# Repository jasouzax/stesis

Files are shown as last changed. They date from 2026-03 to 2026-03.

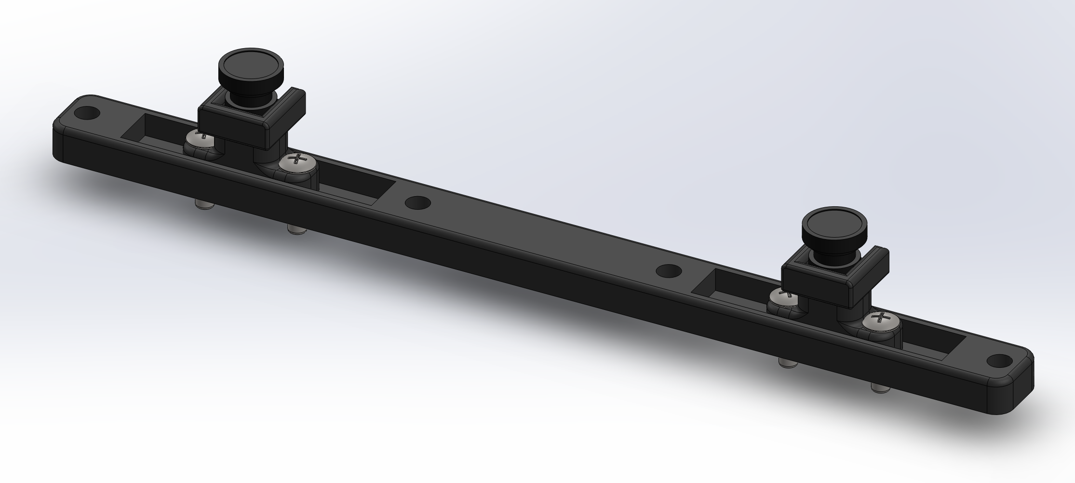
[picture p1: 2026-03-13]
design/images/Screenshot 2026-03-13 at 11.10.45 AM.png

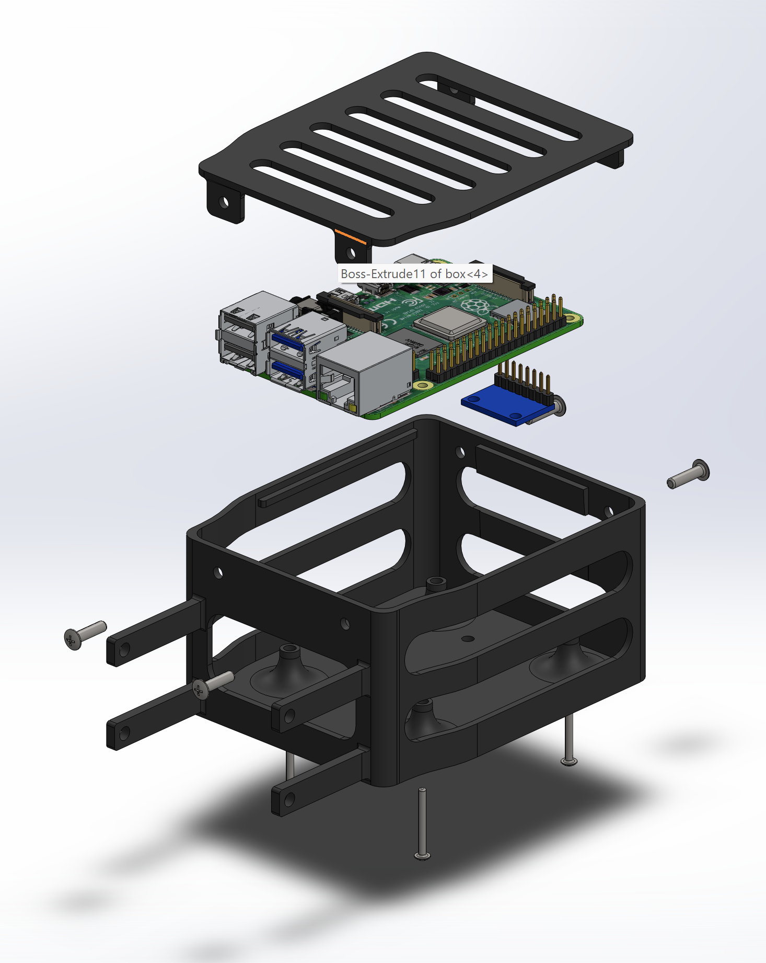
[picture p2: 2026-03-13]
design/images/Screenshot 2026-03-13 at 11.09.35 AM.png

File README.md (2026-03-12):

# Thesis Summary

- [Project Identity](#identity)
- [Project Scopes](#scopes)
- [Problem Statement](#problem)
- [Solution](#solution)
- [Hypothesis](#hypothesis)
- [Objectives](#objectives)
- [Significance of the Study](#significance-of-the-study-rps) *(RPS)*
- [Conceptual Framework](#conceptual-framework)

## Identity

- **Project Name:** Stesis (Stereo-based Sonification Interface System)
- **Thesis Title:** World Navigation Hat – Development of a Wearable Navigation Aid using AIoT for the Visually Impaired
- **Hardware Status:** A single, unified physical prototype is being developed.
- **Publication Strategy:** The research is deliberately split into two distinct papers to prevent copyright and self-plagiarism conflicts:
    - **The IEEE Paper (The Pre-Installed App):** Focuses strictly on the physical navigation algorithm. It evaluates the stereo sonification system, selective filtering via head tracking, and the reduction of sensory overload.
    - **The RPS Paper (The App Manager):** Focuses strictly on the digital/interaction architecture. It evaluates the modular AIoT system, hand-gesture application triggering, server management, and the device's ability to be customized for diverse user needs.

## The Dual-Scope Framework

Because this project addresses the "Valley of death" in Sensory Substitution Devices (sensory limitation/fatigue vs. the generalization problem in real-world environments), it is split into two distinct research tracks.

| Dimension | IEEE Scope (Sensory Limitation) | RPS Scope (Generalization & Integration) |
| --- | --- | --- |
| **Focus** | Minimizing sensory limitations through a radar-like selective filtering algorithm. | Prioritizing AIoT aspects, testing AI/IoT capabilities, and user integration into digital/physical life. |
| **Problem** | Visual Sensory Substitution Devices (VSSDs) fail due to sensory overload, continuously flooding users with audio, preventing "subconscious integration," and causing cognitive fatigue. | VSSDs fail due to integration issues; visually impaired individuals have varied needs, making devices useful only in labs rather than adaptable to real-life scenarios. |
| **Solution** | **Physical Mode (Navigation):** Uses stereo-rectified depth mapping (OpenCV) to convert 3D environments into binaural "radar-like" audio. Local processing ensures <100ms latency. | **Digital Mode (Interaction):** Uses the right camera to detect hand gestures (MediaPipe) to control external AI/IoT applications. |
| **Hypothesis** | Prioritizing selective filtering via intentional head gestures minimizes sensory overload compared to continuous streaming, increasing navigation efficiency and subconscious integration. | Prioritizing a modular system controllable through hand gestures and an IoT server personalizes the device, supporting widespread adaptability. |
| **Objectives** | Develop an AIoT hat minimizing overload via selective filtering. Generate local depth maps via OpenCV. Evaluate cognitive load and navigation efficiency against continuous streaming using a within-subject design. | Build a modular system for third-party AI/IoT apps via NodeJS. Create a toggleable cue mode via hand gestures (MediaPipe) and IMU focus. Test IoT server management, app precision/accuracy, and overall device performance. |

## Objectives (Specific)

- **IEEE** - To develop an AIoT visual sensory substitution hat that minimizes sensory overload by allowing users to selectively filter environmental sonification.
    - Develop a dual-mode prototype powered by a Raspberry Pi 4 that generates local depth maps via OpenCV stereo vision (Physical Mode) and integrates MediaPipe AI hand gesture recognition (Digital Mode).
    - Design a 3D-printed hat mount optimizing weight distribution, powered by a 10,000mAh bank, with modular NodeJS/ElectronJS server for AIoT integration.
    - Evaluate system and user performance using a within-subject design to test the impact of selective filtering on cognitive load and navigation efficiency against continuous streaming baselines.

- **RPS** - To develop an AIoT visual sensory substitution hat that allows applications to be managed in the device with AI and IoT features to allow personalized device to accomidate with Visual Impared People's varied conditions.
    - To build a prototype system that includes:
        - A modular system that allows the development of third party applications for custom modules like AI services, and Server/IoT actions using NodeJS.
        - A toggleable cue mode by hand gesture commands using MediaPipe and using the Inertial Measurement Unit (IMU) to adjust perception focus, to prioritize specific spatial information into audio cues for navigation or to configure external services with the users’ preferences.
        - A stereo rectified sonification system using dual OV5640 stereo cameras and Inertial Measurement Unit (IMU) to convert environmental information through depth maps enabling real-time 3D reconstruction of the environment into audio cues for navigation.
    - To design a portable device that includes:
        - 3D-printed addition on a cap hat to distribute weight evenly and prevent strain on sensitive facial areas like eyes, nose, and ears.
        - Connection to a powerbank placed on the user's pockets to minimize the weight on the head but still power the system
    - To test the functionality of the device system in terms of:
        - Ability to manage applications in the IoT server and its effect in the device
        - Evalulating the Precision, Recall, and Accuracy of the two pre-installed applications of the Toggleable cue interface and the stereo sonification system
        - Measuring the performance of the device running the system

## Significance of the Study *(RPS)*
- **Visually Impaired and Blind Individuals.** They are the primary beneficiaries, gaining increased mobility, safety, and access to digital and social spaces through sensory substitution and IoT assistance.
- **Families and Caregivers.** With the device promoting user independence, caregivers will experience reduced physical and emotional strain while maintaining peace of mind about the user's safety.
- **Medical and Rehabilitation Specialists.** Eye health professionals and rehabilitation centers can use the system as a tool for sensory training and mobility rehabilitation programs, especially to fill in aspects the patient lacks or has trouble with.
- **Researchers and Engineers in Assistive Technology.** The project offers a novel framework that combines virtual world modeling, IoT, and sensory emulation, providing a foundation for future innovations in human-computer interaction and embedded systems. The project can inspire further studies on brain-inspired computing and wearable assistive devices, paving the way for more innovative tools.
- **Government and NGOs for Disability Support.** Organizations involved in disability welfare can adopt or fund similar low-cost solutions to support national accessibility programs and meet inclusive development goals.

## Conceptual Framework 
The IPO of the system is *(Figure 1)*
- **Input**
    - **Hardware**
        - **Raspberry PI 4** - The main microcontroller
        - **10,000mAh Powerbank** - Powers the whole system
        - **Camera (OV5640 5MP/120FOV)** - Captures stereo images in front of the user
        - **Binaural Earphone** - Outputs the binaural audio for user to see through sound
        - **IMU (MPU6050)** - Detects head orientation for interface through head movement
        - **Raspberry PI Cooling Fan** - Responsible for cooling the raspberry PI
        - **3D printed enclosure** - Holds most of the components and sticks to the hat
        - **Hat Cap** - The hat placed on top of the user and holds the enclosure
    - **Software**
        - **VSCode** - Main IDE used in the system's development
        - **Arduino Studio** - Development of the android app for APIs passthough
        - **SolidWorks** - Creates the 3D model of the 3D printed enclosure
        - **GitHub** - Manages the project codebase and files
    - **Connectivity Protocols**
        - **WiFi** - This allows the device to connect to the IoT server, as a hotspot by the phone to provide internet and phone sensor data through the android app
        - **I2C** - Connection to read gyroscoping and accelerometer data from the IMU
- **Process**
    1. Problem Statement
    2. Literature Review (RRL)
    3. Prototype
        1. Requirements
        2. Designing
        3. Development
        4. Refinement
        5. Implementation
        6. Testing
    4. Data Recording
    5. Data Analysis *(IEEE)*
        1. Latency from capture to output
        2. Accuracy of IMU and AI
        3. Stereo Calibration Scopes
        4. Navigation Metrics
        5. Cognitive Load (NASA-TLX)
        6. Intuitiveness (Wilcoxon Signed-Rank Test)
    6. Data Analysis *(RPS)*
        1. Device's performance (weight, latency, etc.)
        2. Server's performance (latency, security, etc.)
        3. Gesture accuracy (head and hand gestures)
        4. Navigation ease of use survey
- **Output** - Development of the wearable navigation aid using AIoT for the visually impared named Stesis
- **Feedback** - Feedback from the output to redesign back to the input as to improve the system

## Related Studies

* [**Louis Commere, and Jean Rouat (2023):**](https://arxiv.org/pdf/2304.05462) The most newest visual sensory subtitution device that both uses depth and sonification, being the most closest to our study and will be used as the baseline to test the null hypotesis. *Limitation:* It provides only localized, single-target directional information, severely restricting global scene comprehension. Users cannot perceive a general room outline simultaneously; instead, they are forced into tedious, sequential "Roomba-like" scanning and must rely heavily on working memory to construct a complete spatial map.
* [**Eye-Tracking Sonification (2025):**](https://doi.org/10.3389/frvir.2025.1598776) Filters VR environments using eye-tracking. *Limitation:* Not tested on real-world visual data; relies on eye movement, which may not be functional for all visually impaired users.
* [**Sound of Vision (2018):**](https://doi.org/10.1097/OPX.0000000000001284) Generates continuous 3D audio-haptic maps. *Limitation:* Suffers from sensory overload affecting long-term adoption. Stesis addresses this via gesture-based filtering.
* [**Eye Cane (2015):**](https://doi.org/10.3233/RNN-130351) Uses infrared for single-point distance sound. *Limitation:* Lacks the spatial context and "scene outline" Stesis provides.

## Theoretical Basis

- **Sensorimotor Contingencies:** Allowing direct control over input shifts cognitive load from conscious decoding to intuitive subconscious spatial awareness.
- **Radar-Like Mapping:** Substitutes 2D visual data into 1D audio by representing the Y-axis as audio and the X-axis as time.
- **Scene Gist and Gestalt Organization:** Humans perceive geometry outlines before details. Stesis uses depth maps via stereo rectification for real-time spatial geometry processing (faster than AI models like MiDaS).
- **Equal Loudness Compensation:** The closest proximity in a time slice is represented in audio; frequency is inversely proportional to proximity, and compensation ensures it doesn't affect volume perception.
- **Head-Related Transfer Function (HRTF):** Volume is split between left/right channels to create 3D space awareness.
- **Focus, Spatial Resolution & Saliency:** Radar scan rate is proportional to the device's angle of depression. Over time, the radar loses total volume to reduce redundant data, prioritizing new movements as visual selective attention.

## System Design

The device first runs the main service which connects to a hotspot or wifi so that it can use server APIs and the internet, then activating the device application running the installed applications. There are two pre-installed applications:
- **Hand Gesture** - This application is activated if the IMU detects that the user is facing to their right hand *(down and rolled/turned facing the right side)*, it captures the right camera and detects the hand guesture through MediaPipe AI. If the hand guesture matches a specific hand guesture then it activates its corresponding action.
- **Stereo Sonification** - This application is activated if the IMU detects that the user is facing downwards indicating they want to see their obstacles to navigate. It captures the stereo images from the two cameras where stereo rectification is applied to generate the depth map, it is then processed to generate a radar map of the environment and then sonified to represent that data as audio to the binaural earphones.
The device can make a request to the server to access these third party applications through an Android phone that provides the internet access and other details like GPS or Compass. The server side hosts to the internet through cloudflare and accepts an API or cargiver/user side access with authentication details of the Device ID and password, the interface shows the third party applications the device installed and other important details like last used or device information for caregiver monitoring.

The device itself contains the following components:
- **Raspberry PI 4** - The central microcomputer running the client side program *(5.5W active, 3W standby)*
- **MPU6050** - The IMU that measures the head orientation *(0.1W active and standby)*
- **OV5640 Cameras** - Placed 13cm apart from each other and provides the stereo images *(2W active, 0.5W standby)*
- **Stereo Earphone** - Provides the audio output generated from the client side program *(0.1W active, 0W standby)*
- **Raspberry PI Fan** - Cools the device and prevents overheating *(0.5W active, 0.2W standby)*
- **Powerbank** - A 10,000mAh powerbank that should be in the user's pockets *(10Ah$\times$3.7V$\times$0.85 efficency=31.45Wh)*
- **Cables/Wires** - Connects each components to each other
- **Case** - A 3d printed case that holds every component except for the powerbank
- **Cap Hat** - The case is glued to the hat to hold everything in place

The expected duration of the device is from 8.27 hours at standby $(\frac{31.45}{3+0.5+0.2+0.1+0}=8.27h)$ to 3.83 hours at continuous active navigation $(\frac{31.45}{5.5+2+0.5+0.1+0.1}=3.83h)$.

The software dependencies of the client side is as follows:
- **Raspberry PI OS** *(OS)* - The main operating system the client device is in
- **Python** *(Programming Language)* - The main framework the client side program is running in
- **Conda** *(Environment Manager)* - Responsible for managing the python environment
- **SocketServer** *(Library)* - To host the client side device info website
- **Requests** *(Library)* - Connects to the server side AIoT server

The pre-installed applications uses these dependencies:
- **OpenCV2** *(Library)* - Does the stereo vision and image processing
- **SMBus** *(Library)* - Allows communication through I2C especially for the IMU
- **Numpy** *(Library)* - Helps manage process data/matrices
- **MediaPipe** *(Library/AI)** - Detects the hand gesture from the image
- **PyAudio** *(Library)* - Connects to the earphones allowing to play generated audio

The codebase of this client side uses a modular design where each module represents a class with their own responsibility, this makes applications their own class with their dependencies being parent classes allowing easy tracking of application dependencies. The pre-installed modules are:
- `main.py` (loads `hand` and `audio` because their applications) - This module hosts the device info website and switches between the depth map sonification processes `audio` and the modular application calling `hand` based on the reading of the IMU
- `config.py` - This is where all of the configurations of the device is stored in
- `camera.py` (from `config`) - This module connects to the stereo cameras to read the images
- `imu.py` (from `config`) - This module reads from the IMU through I2C and processes the device orientation details
- `calibrate.py` (from `camera`) - This module is ran directly to calibrate the depth map generation by generating the stereo rectification JSON `stereo-{baseline}.json`
- `depth.py` (from `camera`) - This module generates the depth map by using the `stereo-{baseline}.json`
- `radar.py` (from `depth` and `imu`) - This module maps the depth map to the radar map
- `audio.py` (from `radar`) *(Main Application)* - This module sonifies the radar details as audio output to the earphones
- `hand.py` (from `camera`) *(Main Application)* - This module detects the hand guesture of the right camera through MediaPipe AI, and triggers their associated action
- `rrl_kchr2023.py` (from `camera`) *(IEEE only)* - This is the algorithm based on (Louis Commere, and Jean Rouat 2023) to be ran on State A as a comparision to the research's algorithm.

The device connects to the AIoT server through an Android phone that hosts the hotspot, providing the internet, GPS, Compass, etc. The software dependencies of the android phone are as follows:
- **Kotlin** - Programming language to program the app logic/server.
- **Google Mobile Services (GMS)** - Provides APIs for the app to forward to the device like `play-services-location` for GPS location.

The server side uses the following software dependencies:
- **NodeJS** - The main framework of the server side process
- **TypeScript** - Allows stricter type checking to prevent server side issues
- **ElectronJS** - Creates an application compiled format, and allows advance API/Automation
- **Ollama** - Connects with Langauge Models for advance intellegence requests
- **Cloudflare** - Allows server to be hosted through a cloudflare tunnel through tunneling

For the softwares/tools used for development includes:
- **VSCode** - IDE for developing client-side and server-side codebases
- **Android Studio** - The software used to develop the android application
- **SolidWorks** - CAD software to develop the 3d case model
- **Github** - Manages the entire codebase, versions, and distribution

## Stereo Rectification Calibration

To calibrate the stereo vision, 3 baseline was tested 8.75cm (minimum), 10cm, and 13cm (maximum). For image training/calibration, 22 images where provided where 9 of them are the sides top/middle/bottom and left/middle/right, for both close and far (so total 18). Four other images angled top, bottom, left, and right were added totaling 22 images. The statistics like Root Mean Square (RMS) pixel error and minimum/maximum detectable range are:

| Baseline (cm) | Calculated (cm) | RMS Both (px) | Minimum (cm) | Maximum (cm) | FOV Left | FOV Right | RMS Left (px) | MS Right (px) |
| - | - | - | - | - | - | - | - | - |
| 8.75 | 8.7861 | 1.7393 | 7 | 90 | 112 | 112.88 | 1.3914 | 1.3963 |
| 10 | 10.66 | 1.5494 | 15 | 100 | 113.19 | 113.32 | 1.2314 | 1.2314 |
| 13 | 13.0646 | 1.4055 | 24 | 130 | 112.52 | 111 | 1.0852 | 1.181 |

Since the equation for depth $Z=\frac{f\cdot b}{d}$ shows that depth is linear if the focal length $(f)$ and baseline $(b)$ are constant, the minimum and maximum depth for a specific baseline can be represented as $Z=Ab+C$. Through assuming linear trend the minimum depth is $Z_{min}=4b-26.5$ while the maximum depth is $Z_{max}=9.3b+8.5$. Since our target range is for close quarter navigation (rooms, corridors, buildings, etc.) 130cm max depth detection is perfect for range detection, even for close outdoor navigation.

## Benchmarking & Testing *(IEEE)*

The study employs a **Within-Subject** design with 40 blindfolded participants comparing **State A** (Continuous Stream) vs. **State B** (Stesis Selective Filtering) on a controlled obstacle course (Our school classrooms and corridors). As for the modular system, the user test if they could successfully call a mockup call through hand gesture.

**Comparitive/Baseline Methods (State A)**
Continuous streaming will implement existing visual sensory substitution to audio algorithms to provide a better comparision to the Stesis Selective Filtering algorithms. The algorithm is based on [Louis Commere, and Jean Rouat (2023)](http://arxiv.org/pdf/2304.05462) which uses the beep-repetition rate has it remains the gold standard baseline for non-verbal spatial warning systems.

**System Performance Metrics:**

- **Latency:** Time from capture to audio output (Target: <100ms).
- **Accuracy:** Reliability of Head (MPU6050) and Hand (MediaPipe) gesture recognition.

**User Performance Metrics:**

- **Navigation:** Time to Completion (TTC), Obstacle Hits (OH), and Veering (lateral deviation).
- **Cognitive Load:** NASA-TLX (Task Load Index) survey to quantify mental fatigue.
- **Intuitiveness:** Wilcoxon Signed-Rank Test on user feedback.

**Statistical Analysis:**
A Paired T-Test will be used for TTC and OH. If the null hypothesis is rejected, indicating that gesture-based filtering significantly improves performance.

## Benchmarking & Testing *(RPS)*

- **Testing Methodology:** Users test the modular system by attempting to successfully trigger a mockup call through a hand gesture.
- **Application Management:** Evaluating the system's ability to manage applications within the IoT server and its overall effect on the device.
- **Hardware & Server Performance Metrics:** Measuring the physical device's performance (such as weight and latency) alongside the IoT server's performance (including latency and security).
- **Interface Accuracy Metrics:** Evaluating the Precision, Recall, and Accuracy of the two pre-installed applications (the toggleable cue interface and the stereo sonification system) as well as the gesture accuracy for both head and hand movements.
- **User Experience:** Conducting a navigation ease-of-use survey.

## Implications and Future Work

- **Digital Integration:** Potential for managing social media interfaces, text recognition, and API integration via gestures.
- **Hardware Evolution:** The selective filtering software concept can be adapted to existing smart glasses using LiDAR or eye-tracking.
- **Future Interventions:** Exploring hybrid audio-tactile feedback to reduce fatigue and conducting longitudinal studies with visually impaired users. This prototype is a foundational validation of the controllability hypothesis.

## Design Backstory & Rationale

- **The Hardware Pivot:** The prototype utilizes a **Raspberry Pi 4** rather than the smaller Orange Pi Zero 2W. While the Orange Pi offered better portability, it presented critical stability issues (WLAN failures on Debian, I2C kernel conflicts) that hindered development. The RPi 4 provides the architectural stability necessary to validate the *software hypothesis* (selective filtering), which takes precedence over miniaturization in this phase.
- **Why a Hat?** Distributing hardware weight across the cranium avoids the nose/ear fatigue common with smart glasses. Additionally, the stereo camera spacing on the brim mimics the natural separation of human eyes, aiding the brain in depth perception and sonification.
- **Nomenclature:** "Stesis" is a triple-entendre: **Ste**reo-based **S**onification **I**nterface **S**ystem, while the suffix "-sis" nods to its dual nature as a Thesis and a Hypothesis.

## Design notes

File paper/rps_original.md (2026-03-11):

  
**World Navigation Hat \- Development of a Wearable Navigation Aid using AIoT for the Visually Impaired**

An Undergraduate Design Project Proposal Presented to Faculty of the Computer  
Engineering Department of College of Technology University of San Agustine

In Partial Fulfillment of the Requirement of the Course  
**CPE 413 \- CpE Practice and Design I**

**By:**  
Daywan, Vince Ginno B.  
D’Souza, Jason C.  
Pabito, Ethel Herna C.  
Wang, ChenLin

Engr. Glenda S. Guanzon  
November 2025  
**Introduction**

# **Background of the Study**

Visual impairment is a global health problem that significantly affects individual's daily lives by impeding independent navigation, social interaction, and overall quality of life (Theodorou et al., 2023). There is an estimation of 2.2 billion people globally who are identified as visually impaired and this number could still increase to 2.5 billion by 2050 as stated by the World Health Organization (World Health Organization, 2023). In the Philippines, 2.17 million Filipinos are identified as visually impaired as quantified by reports from the year 20218 from the Philippines Eye Research Institute (PERI) and Department of Health (DOH) (Shinagawa Lasik & Aesthetics, 2025). Visual impairment does not pertain to total blindness. According to World Health Organization (2023), visual impairment can be identified and categorized based on the presenting visual acuity; 

a) Mild Vision Impairment, as visual acuity is better than 6/18, 

b) Moderate Vision Impairment, as visual acuity is worse than 6/18 but better than 6/60, 

c) Severe Vision impairment, as visual acuity is worse than 6/60 but better than 3/60, 

d) Blindness, as visual acuity is worse than 3/60, types such as blindness with light perception, individuals can only perceive light, and total blindness, individuals who have no light perception. 

Other common types include astigmatism, near-sightedness (myopia) and far-sightedness (hyperopia), which account for a large share of impairments, alongside conditions like cataracts, glaucoma, and age-related macular degeneration (AMD), with AMD alone affecting 8.06 million people globally in 2021 (Zou et al., 2024).

Navigation is one of the problems visually impaired people (VIP) encounter, they often have difficulty crossing the road and tracking their location, as well as experiencing accidents, falls, and collisions (Ikram et al., 2024; Gao et al., 2025; Muhsin et al., 2023).   
In addition, VIPs experience social isolation and reduced access to information, limiting their educational and employment opportunities (Arvind, 2023). There are already existing solutions or aids for VIPs, for daily assistance, which include guide dogs, white canes, and electronic travel aids (Muhsin et al., 2023). Additionally, one of the technologies VIPs depend on for navigation is assistive devices, which use sensory substitution to convert visual information into auditory or tactile cues to provide spatial awareness (Skulimowski, 2025). These devices often incorporate IoT sensors to capture real-time environmental data, providing navigational assistance in complex environments (Real & Araújo, 2023).

Sensory substitution devices (SSDs) are assistive wearable devices that can be eyewear, a vest, or a hat, allowing VIP users to perceive their surroundings by converting sensory information from one modality to another (Mishra et al., 2025). These SSDs are embedded with sensors that allow obstacle detection, navigation, and object recognition, enhancing VIPs' daily independence and reducing their reliance on traditional aids (Tokmurziyev et al., 2025). However, global adoption of these devices is limited due to cognitive overload performance, extensive training needs, ergonomic discomfort design, and the lower processing bandwidth of non-visual senses compared to vision (Hou et al., 2025).

# **Rationale**

Visual Impairment encompasses a spectrum of conditions, from moderate vision loss to complete blindness, which significantly impacts an individual's ability to perceive their environment and perform daily activities (Kumar et al., 2025). This condition also affects the individual’s social interaction and overall quality of life (Que et al., 2025). More than 2.17 million people in the Philippines live with visual impairment, which restricts their perception, mobility, navigation, and accessibility to information—depriving them of work opportunities and independence (Chavarria et al., 2025). To mitigate the challenges encountered by the VIP, assistive technologies and rehabilitation strategies have been developed (Skulimowski, 2025). Traditional assistive aids like white canes offer limited feedback, initiating the development of electronic travel aids that deliver richer environmental information and improve autonomous navigation (Chandra et al., 2025). Another solution is a wearable SSD, an assistive technology that an individual can wear on their body to help users navigate both their physical surroundings and digital applications, and emerging as a potential avenue to restore or gain a sense of spatial perception or awareness and navigational ability (Skulimowski, 2025). Additionally, SSDs promote social interaction that aligns with one of the United Nations' Sustainable Development Goals for health and equality (Xue et al., 2025).

In previous studies, SSDs have been limited in their applicability, as existing devices often perform poorly in real-world situations, encountering cognitive overload problems that overwhelm users with excessive information, making navigation difficult (Arora et al., 2024). Another identified concern is that the SSD design is uncomfortable, as it is bulky and requires extensive training, which limits its practicality (Gao et al., 2025; Muhsin et al., 2023, p. 148). In addition, many of these devices lack digital integration as capabilities, focusing mainly on obstacle detection and not connecting well with digital tools (Makati et al., 2024). These deficiencies underscore the pressing need for higher SSDs that can outperform and enhance existing devices. Therefore, a need for development of optimized smart navigation devices improves the functional efficiency and performance of SSDs without overlooking the previous concerns like overloading data processing.

In this study the researchers aim to address these matters through the development of a wearable navigation hat integrated with AIoT, which introduces a smart navigation hat that uses 3D data to give audio feedback and connects to IoT services for navigation in both physical and digital environments. Furthermore, it enhances sensory processing, focusing on reducing cognitive overload in the system and making navigation simpler for VIP users. Additionally, the hat features customizable options, including a modular operating system that allows users to choose between hand gesture or voice commands.

# **Objectives of the Study**

## **General Objective**

To develop an AIoT visual sensory substitution hat device that converts real-time environment information through emulating human sensory processes into audio cues for the VIP.

## **Specific Objectives**

1) To build a prototype system that includes:  
1) A photogrammetry (2D to 3D) system using dual OV5640 stereo cameras and Inertial Measurement Unit (IMU) to convert environmental information through depth maps enabling real-time 3D reconstruction of the environment into audio cues for navigation.  
2) A toggleable cue mode by hand gesture commands using MediaPipe and using the Inertial Measurement Unit (IMU) to adjust perception focus, to prioritize specific spatial information into audio cues for navigation or to configure external services with the users’ preferences.  
3) A modular system that allows the development of third party applications for custom modules like AI services, Server actions using NodeJS, and hand gesture recognition.

2\)	To design a portable device that includes:

1) A rechargeable 5V/3A UPS module with 18650 lithium-ion batteries for cord-free operation via Type-C charging.  
2) 3D-printed hat enclosure to distribute weight evenly and prevent strain on sensitive facial areas like eyes, nose, and ears.

3\)	To test the functionality of the device system in terms of:

1) Calculating the Error and Success Percentage performance of photogrammetry by comparing the generated depth maps to ground truth measurements.  
2) Evaluating the Precision, Recall, and Accuracy of the toggleable cue mode hand gesture commands responsiveness to switching modes.  
3) Measuring the frame per second (FPS) of AI processing, error rates in recognition, and route accuracy of the modular system.  
4) Simulating full system functionality by combining photogrammetry, IMU, and modules to track overall FPS, audio cue fidelity, and failure cases, with qualitative feedback from the users using surveys.

# **Significance of the Study**

This project device will specifically benefit to the following:  
**Visually Impaired and Blind Individuals.** They are the primary beneficiaries, gaining increased mobility, safety, and access to digital and social spaces through sensory substitution and IoT assistance.  
**Families and Caregivers.** With the device promoting user independence, caregivers will experience reduced physical and emotional strain while maintaining peace of mind about the user's safety.  
**Medical and Rehabilitation Specialists.** Eye health professionals and rehabilitation centers can use the system as a tool for sensory training and mobility rehabilitation programs, especially to fill in aspects the patient lacks or has trouble with.  
**Researchers and Engineers in Assistive Technology.** The project offers a novel framework that combines virtual world modeling, IoT, and sensory emulation, providing a foundation for future innovations in human-computer interaction and embedded systems. The project can inspire further studies on brain-inspired computing and wearable assistive devices, paving the way for more innovative tools.  
**Government and NGOs for Disability Support.** Organizations involved in disability welfare can adopt or fund similar low-cost solutions to support national accessibility programs and meet inclusive development goals.

# **Conceptual Framework**

[**Figure 1**](https://docs.google.com/document/d/1N4Ya048OJufQJaMhjFfynmU-Aq_rgIfC3wOmSFFCeBE/edit#figur_ipo)  
*IPO Model of the Conceptual Frame of the Study*

Figure 1 illustrates the study's conceptual framework as an Input-Process-Output (IPO) model. Starting with three kinds of required input, such as the hardware components Microcontroller, Sensors, Actuators, SIM Module, and Wireless Connectivity, used on the device, which can be either 2/3G used for deployment doors, or Wi-Fi as used in deployment indoors or development. In addition to the input, the software components include Project management, Client-side device, and Server-side device. After the input, it will proceed to the process, which includes the following: 1\) Problem Statement, 2\) Literature Review, 3\) Prototyping, which includes Materials Requirements, Device Design, Development, Refinement, and Implementation, 4\) Data Recording, 5\) Data Analysis of the findings using P-test on the Device Performance in terms of accuracy in recognizing user controls (hand gestures) and generating relevant audio from environmental inputs; Sensory Overload on user accuracy in interpreting generated audio cues (e.g., via task completion rates) and qualitative feedback on perceived overload on user; Sensory Fatigue on usage duration before symptoms like headaches emerge (e.g., via self-reported scales, physiological monitoring, or user surveys); Sensory Integration in tracking reaction times to environmental data, learning curves over sessions, and survey responses on ease of subconscious adaptation. The research process mimics typical development cycles, including literature review, prototyping, designing, testing/evaluation, and implementation. By the end of each iteration, the researchers expect to be closer to the end goal, with user and professional feedback to start the cycle again until the end goal of a wearable navigation aid is achieved.

# **Theoretical Framework**

This research attempts to solve an issue facing most Visual Sensory Substitution Devices which is primarily about the issue on translating a high bandwidth visual information to low bandwidth audio information without causing overstimulation, our novel solution is the emulate the human sensory mechanism to carry the processing load from the user and ensure that substituted information is minimal and necessary to the user. The theoretical principles include:

**Focus and Spatial Resolution (Foveation)**   
The human vision has a tiny high-resolution fovea covering around 1 to 2 degrees of the visual field but accounts for around half of visual cortex (Himmelberg et al., 2023), outside this region is a much coarser peripheral vision where acuity drops rapidly (Aydin et al., 2024). In this study, the device attempts to mimic this by using a focus point system where the user can contain the focus radius indicating that area of the environment the user wants to be translated into audio and at what detail.

**Selective Attention and Saliency**   
As the visual system cannot process all details at once, it selectively attends to salient or task-relevant features, this is done by implementing a bottom-up saliency and top-down goals to filter out redundant/irrelevant information (Arora et al., 2025). This demonstrates that people focus on key objects ignoring uniform backgrounds as the nervous system "tunes out" repeated stimuli and amplifies novel/focused ones (Gershman, 2024). The device translates environmental information where any stagnating/constant information must be tuned out over time leaving behind changes indicating motion.

**Scene Gist and Gestalt Organization**

Human vision rapidly extracts the gist (background) and figures (foreground) from a scene within the first fixation (\~36ms) with around 80% accuracy (Loschky, 2025). This process is done through Gestalt principles that groups elements to simplify complex images such as by similarity, proximity, common region, continuity, etc. (User Testing, 2024). This indicates that the device should be able to generally/primitively separate the environmental data into background and foreground categories where foreground can then be separated into groups, this is information to indicate the translated audio.

**Parallel Motion vs. Detail Pathways**   
Human visual systems process motion and details in two separate channels, the magnocellular pathway for fast motion and size but in less detail, and the parvocellular pathway for static objects in more detail (Al-Najjar et al., 2022). Suggests that when the device switches to motion detection it should prioritize the speed, size, and direction of that motion.

**Temporal Dynamics and Scanning**  
Vision is not a singular static snapshot but rather a continuous sample of the world via eye movements has humans typically shift gaze 3-4 times a second (Nghiem et al., 2025). Thus, in this study, the device should rapidly provide updating audio to allow temporal integration rather than one large static soundscape all at once, this also solves the issue of cognitive overload and sensory fatigue.

**Multisensory Integration**   
The brain integrates additional senses like auditory, vestibular, and proprioceptive senses to form a coherent representation of the environment (Multisensory Integration, 2025). Thus, the device should align with those senses to prevent conflicting senses that could often cause nausea. This could be in the form of aligning the virtual environment with IMU to align with vestibular senses, or lower the output audio when the user is focusing on something else like talking to others.

**Scope and Delimitation**  
This research study focuses on Sensory Substitution Devices, more specifically on Vision Substitution. The device aims to fill in what different variety of visually impaired individuals lacks, like if fully blind the device should be able to act as an “artificial eye” providing information the person wants, or if the person is near sighted it could read text from afar from the user and warn of objects rapidly approaching the user, and so on. This is done by having a modular system running the main pipeline, the main pipeline inputs images from the stereo camera, depth map it to a virtual-physical map, follows an algorithm to emulate human vision processes, and finally generates the necessary audio cues for the individual. This pipeline allows applications to take into account more varied needs such as hand gesture recognition to control the parameters of the main pipeline so the person can navigate the device without seeing anything, image recognition to read text near or far, face recognition to recognize friends and family, and even more personalized interest like keeping track of location. In the testing, the device will only prioritize the functionality and feasibility of the system to determine if the designed and developed project can perform efficiently. Mock API will be utilized to demonstrate the potential functionality of external services of the system. 

# **Review of Related Literature**

Zvorișteanu et al. (2021) presented the Sound of Vision (SoV) system. It is a wearable SSD designed to aid VIPs in spatial cognition and navigation, using stereo-vision-based 3D reconstruction to interpret the environment and translate spatial data into audio and haptic cues. The device integrates a stereo camera, an infrared depth sensor, and an inertial measurement unit (IMU) to track the motion of the user’s head and the installed camera mounted on the headgear, using these as its inputs. Furthermore, the output audio and haptic feedback are delivered via headphones and a haptic belt. The device processes visual data in real time using GPU-accelerated computation to reconstruct the 3D Environment and identify obstacles via segmentation algorithms based on disparity and histogram analysis. The depth of each pixel is determined by the stereo disparity formula Z=f⋅Bd, where Z is the depth, B is the baseline, f is the focal length, and d is the disparity. The SoV converts environmental data into audio-haptic cues, allowing users to detect obstacles, open spaces, and open areas. In testing the device's performance with the visually impaired participants, it showed a 10% improvement in depth accuracy and an 88.5% task success rate compared to standard stereo vision methods. The results highlight the device's effectiveness in real-world navigation and its potential to enhance mobility and spatial awareness compared to traditional aids such as white canes.

Sami et al. (2025) developed a smart wearable (hat) assistive device that integrates object detection with voice-assisted navigation to support VIP in real-time spatial awareness. The device uses an ESP32-CAM module to capture live video and transmit it via Wi-FI to a mobile application that employs a TensorFlow-based deep learning model for efficient object recognition. The camera-detected objects are then processed into audio prompts that send alerts to the user when there are nearby obstacles and provide navigation directions. The programmed system produced a seamless object-detection-to-voice pipeline. The Smart Hat's system architecture demonstrates the integration of an IoT processing method to enable wireless communication between the smart hat and the user interface for remote processing and real-time updates for the user. Testing results show an object detection accuracy of over 91%, highlighting the reliability in dynamic environments. In addition, the Smart Hat device offers compact, low-cost, and user-friendly features. It demonstrates how IoT-enabled computer vision can transform traditional assistive technologies into intelligent, voice-guided navigation tools for the visually impaired.

RealSense (2025), in collaboration with Eyesynth, developed a wearable sensory-substitution device designed to enhance spatial awareness and independent navigation for visually impaired users by converting real-time 3D spatial data into bone-conduction audio cues. The device employs the RealSense D415 depth camera to capture real-time 3D depth data calculated using the stereo disparity formula Z=f⋅Bd. Then it is processed to generate a point cloud representation of the surroundings, where each depth pixel being mapped to 3D coordinates using the equation X=u-cxzfx, Y=v-CyZfy, Z=Z to provide a complete spatial surrounding rather than a 2D view. The point-cloud data conjoint with the inertial and head motion tracking, is then processed through an onboard ASIC and Simultaneous Localization and Mapping (SLAM) modules to identify object orientation, translating them into audio signals such as pitch (height), volume (distance), and stereo panning (lateral position), allowing users to perceive objects and obstacles up to 5 meters away without external infrastructure. In testing NIIRA, it demonstrated improved independence and navigation in both indoor and outdoor environments, adapting to users’ preferences, and displayed high obstacle-detection accuracy, minimal processing latency, and enhanced independent navigation. The participants reported that the bone-conduction audio feedback provided a clear environmental awareness without blocking external sounds.

Udayakumar et al. (2025) designed a Smart Vision Glasses (SVG) that processes environmental input data using AI, LiDAR depth mapping, and computer vision algorithms. The device’s front-facing camera captures visual data, while the LiDAR sensor measures real-time depth information using the principle of Time-of-Flight (ToF) – where the distance (D) is calculated using the formula D=c⋅t2, where c represents the speed of light and t the time taken for emitted light to return after reflection. These depth and image data are then processed through an AI-based recognition model that uses Convolutional Neural Networks (CNNs) to classify objects, text, and faces within the user's field of view. The recognized elements are subsequently analyzed and prioritized based on proximity and relevance using the LiDAR-assisted spatial mapping, which produces a semantic understanding of the scene; implementing Volume of Interest (VOI), a controllable spatial region or focus radius that limits feedback, to prevent sensory overload, enhancing user focus in dynamic environment. This processed information is then transmitted to a smartphone-based application converting the recognized data into voice audio cues through text-to-speech (TTS) engine. The device applies natural language processing (NLP) principles to ensure that the audio output is contextually meaningful and user-friendly. The input-output process follows a sequential pipeline:

1) capture of the image depth data  
2) AI-driven detection and classification  
3) distance estimation through the ToF equation  
4) conversion of results into voice audio output describing nearby objects, text, or faces. 

The SVG through hearing supports the four primary modes – “Thighs Around You”, “Reading”, (Walking Assistance), and “Face Recognition”. The SVG is also equipped with gesture and voice control interfaces, allowing users to switch modes or issue commands hands-free, enhancing accessibility and user interaction. A multicenter usability study was conducted across five rehabilitation centers in India, involving 90 participants with a mean age of 23.5 years, to test the device functionality. The participants tested the four primary modes by completing real-world navigation and recognition tasks, and their feedback on the device's usability and helpfulness was also recorded. Results showed that 72.9% indicated that "Reading” mode is helpful, 44.7% for “The Things Around You”, 36.5% for “Face Recognition”, and 22.4% for “Walking Assistance”, showing that the device effectively enhances environmental awareness, reading ability, and object identification.

Ruan et al. (2025) developed a multifaceted sensory substitution wearable device that uses an audio-based curb detection to improve real-time awareness and navigation safety for individuals who are blind or have low vision. The device integrates a stereo camera, ultrasonic range sensors, and inertial motion units (IMUs) to identify curbs and ground-level transitions Adapting the stereo disparity formula Z=f⋅Bd, the system calculates the curb height and distance, while the ultrasonic sensors confirm the surface proximity of the environment for redundancy and accuracy. The sensory data are processed and converted into audio and vibrational cues, where the pitch and repetition rate of the sound correspond to the curb’s distance and height, providing intuitive, time-sensitive feedback. In the pilot testing, 12 participants were involved, 8 with blindness and 4 with low vision. The participants tested the navigation feature of the device in both indoor and outdoor test environments, including simulated sidewalks, ramps, and descending curbs. After testing, the performance statistics of the device showed an average curb detection accuracy of 94.3%, with a false-negative rate of 3.7%, and an average alert response time of 1.2 seconds, indicating the system’s reliability in detecting and signaling curbs in real time. Participants reported that it also improved confidence in mobility and reduced the risk of missteps or trips. This demonstrates that the audio-based curb detection approach driven by LiDAR-like depth estimation and multimodal feedback effectively enhances real-time alerting and safe navigation for the VIP.

Viancy V et al. (2024) introduced AuralVision, a wearable assistive device that is designed as eyewear to improve navigation for visually impaired individuals by incorporating object detection, scene classification, and reinforcement learning. The device's system architecture includes a camera sensor to capture the user’s environment, image-processing and object-detection software to classify obstacles and identify significant objects, and an audio module to translate detection results into auditory cues for navigation. Utilizing a convolution neural network (CNN) approach or deep learning-based vision algorithms trained on the Object Net 3D dataset to interpret the surrounding environment and convert the visual information to auditory cues that convey spatial awareness. AuralVision uses 3D visualization and sound-based feedback to identify objects, classify road scenes, and assist users with obstacle avoidance and pathfinding. The device adapts to dynamic environments through continuous learning, thereby improving navigation decision-making.

Hamilton-Fletcher et al. (2021) developed a mobile sensory-substitution device called SoundSight. This device translates input color, depth, and temperature data into output audio cues, allowing the visually impaired users to sense their environment. The system captures environmental input using a mobile with an RGB-D camera and a thermal sensor. Then it processes the data stream through a multi-feature mapping pipeline before integrating it into a composite audio stream. Depth is calculated using the stereo disparity formula to determine the distance of the object from the user's perspective. At the same time, the RGB camera's color hue values are mapped to sound pitch using the equation fc=kc×H, where H represents the hue intensity and scaling constant. Temperature measurements are converted to amplitude modulation through At=kt×T, where T is the sensed temperature and kt is a sensitivity coefficient. These parallel mappings are integrated using the data fusion algorithms, synchronizing depth, color, and thermal inputs before generating the composite audio streams that encode environmental depth through rhythm, color through pitch, and temperature through loudness. In testing the device's functionality, 15 blind and 10 low vision participants are involved. The device demonstrated rapid user learning and over 85% recognition accuracy, demonstrating that the multi-feature sonification can reliably convey complex environmental information.

Han et al. (2025) designed a Multi-Path Sensory Substitution Device (MSSD) that enhances low-vision mobility and virtual navigation of the visually impaired people by integrating real-time depth mapping, IMU-based motion tracking, and depth optimization algorithms. The system processes input from a depth camera and inertial sensors to create a 3D spatial model of the environment, using the stereo disparity equation to calculate object distance and the projection model X=u-cxzfx, Y=v-cyzfy, to map each pixel to world spatial coordinates. After acquiring the data from the processed input, it generates a 3D point cloud, which then is converted into an occupancy grid for spatial awareness, while the IMU readings refine user orientation using the equation t=t-1+ωtΔt. A modified A\* (A-star) algorithm is used to compute the optimal navigation routes using the cost function fn=gn+hn, balancing actual distance and heuristic estimates to avoid obstacles. The selected virtual path is then translated into audio-haptic feedback, where the vibration intensity and sound frequency indicate direction and proximity, using speakers or headphones to create output data directional audio cues and vibration motors/haptic actuators for tactile feedback. To check the device's functionality, the researchers tested it with 20 low-vision participants. The system attained a result of 91% path following accuracy and a 38% reduction in navigation errors. As the device demonstrates a satisfactory functional performance, this indicates that combining 3D mapping, motion sensing, and heuristic path planning effectively supports real-time, safe, and virtual navigation for the visually impaired individuals.

Commère & Rouat (2023) evaluated five depth-to-sound sonification methods to compare their performance and effectiveness. One of the methods evaluated is the LiDAR-to-repetition-rate sonification model. The identified sonification model converts visual information into rhythmic auditory cues, helping visually impaired individuals to develop a sense of spatial awareness through sound. Using the Time-of-Flight (ToF) equation D=c⋅t2, the model measures the distance of an object and maps it inversely to the beep repetition rate R=kD, where R is the repetition rate (Hz), D is the distance (meters), and k is a scaling constant which is determined experimentally to maintain the perceptible tempo differences between near and far objects which results if an object is closer it generates faster repetition rates or beeps and far detected objects have slower rhythm beeps which the model’s spectrogram design reflects this relationship. Whereas the temporal density (number of pulses per second) indicates proximity, while frequency and amplitude encode additional object features such as height and reflection intensity, creating a dynamic “rhythmic depth map” that represents distance through time spacing between sound bursts—in experimental testing with 28 sighted but blindfolded participants, a three-phase protocol consisting of Depth Estimation, Azimuth Estimation, and Retention Assessment confirmed that repetition-rate sonification produces the lowest mean absolute error (MAE) in distance perception and was the most intuitive and accurate among the other mapping methods like frequency or amplitude-based cues. The results finding revealed a strong inverse correlation between the perceived distance and repetition rate (R∝1D), indicating that LiDAR-driven rhythmic approach effectively translates the spatial depth into comprehensive sound patterns, offering an enhanced basis for real-time auditory sensory substitution systems for the visually impaired.

Zhao et al. (2025) conducted a clinical evaluation of an assistive device, a wearable electronic navigation aid (ENA), for visually impaired individuals through a prospective, non-randomized, single-arm, open-label trial involving 30 participants (each participant was given five trials for each functional task), selected through purposive sampling to ensure that individuals with blindness or severe visual impairment could assess the performance of the assistive device. The study primarily focused on the functional efficacy of the device, assessing how effectively it supports navigation and daily tasks of the visually impaired users. The assistive device used in testing integrates ultrasonic sensors, vibration motors, and audio output components. The study implemented a structured, protocol-guided or functional evaluation framework that combined quantitative measures including accuracy rate (Successful TrailsTotal Trails×100), error rate (Navigation ErrorsTotal Trails×100), reaction time (RT=Tresponse-Tstimulus), task completion time (TCT=Tend-Tstart), and performance improvement rate (PIR=Post Test \- Pre TestPre Test×100) to assess navigation accuracy, responsiveness, and efficiency objectively, supported by qualitative user feedback on comfort, usability, and confidence. The study reveals that the ENA device effectively improved safe navigation and mobility performance for visually impaired users.

**Summary**  
Recent studies (2019–2025) on assistive technologies for the VIP highlight wearable and mobile devices utilizing a sensory substitution approach to convert visual/spatial data into audio, haptic, or multimodal cues, applying stereo vision (e.g., disparity formula Z=f⋅Bd), depth sensors like LiDAR/ToF (e.g., D=c⋅t2), AI-driven computer vision (e.g., CNNs, TensorFlow), and IMUs. This approach expresses the outcome produced by the device such as real-time obstacle detection, object recognition, and navigation, similar to the Caraiman et al.'s Sound of Vision (SoV), which addresses sensory overloading via a controllable focus radius (VOI) and modular components for partial generalizability; Sami et al.'s Smart Hat for cost-effective voice output; RealSense's NIIRA point-cloud processing to semantic audio; Commère and Rouat's LiDAR sonification for rhythmic depth cues; Hamilton-Fletcher et al.'s SoundSight for mobile timbre/volume mappings; Ruan et al.'s curb detector for 94.3% accuracy; Han and Li's Multi-Path Sensory Substitution Device (MSSD) for 91% path accuracy; Zhao et al.'s electronic navigation aid (ENA); and Udayakumar and Gopalakrishnan's Smart Vision Glasses (SVG) for AI-LiDAR voice modes. However, systems like AuralVision that utilizes ToF lasers for bone-conduction stereo sound, lab-effective but range-limited, Eyesynth’s NIIRA object recognition process prone to overload without human emulation, Depth Sonification repetition rates for intuitiveness, SoundSight LiDAR/thermal to audio which is app-constrained, Smart Hat that is non-modular, and multi-faceted SSDs with 85% curb accuracy often face issues like sensory overload, training demands, limited real-world adaptability, and lack of digital-physical navigation. These studies proposes an idea that work closely aligns with SoV by tackling sensory overloading through VOI and modular components but advances it by explicitly mimicking human perception via a modes system and a modular IoT pipeline that applications can embed for navigation in both physical and digital worlds, addressing SoV's training needs and real-world performance gaps while incorporating brain emulation for superior overload reduction and versatility, building on these predecessors to offer a more intuitive, scalable solution for VIP independence. In addition, evaluations across studies ranging from 12 to 90 participants showcase 85% to 95% accuracies and qualitative benefits like reduced errors (e.g., 38% in MSSD). These studies introduce an innovative and improved SSD by adding brain emulation, AI, and IoT for advanced overload reduction and versatility.   
**Table 1**  
*Differentiation Table 1*

| Components | Zvorișteanu et al. (2021) | Sami et al. (2025) | RealSense (2025)  | Udayakumar et al. (2025)  | Ruan et al. (2025) | World Navigation Hat  |
| :---- | ----- | ----- | ----- | ----- | ----- | ----- |
| Zero Form Single Board Computer |  |  |  |  |  | **✓** |
| LiDAR Sensor |  |  | ✓ | ✓ |  |  |
| Depth / RGB Camera | ✓ |  | ✓ | ✓ | ✓ | **✓** |
| IMU | ✓ |  | ✓ |  | ✓ | **✓** |
| Computer Vision / AI | ✓ | ✓ | ✓ | ✓ | ✓ | **✓** |
| Audio Output (Earphones / Bone-Conduction) | ✓ |  | ✓ | ✓ | ✓ | **✓** |
| Object Detection / Distance Estimation | ✓ | ✓ | ✓ | ✓ | ✓ | **✓** |
| Mobile / Wearable Form | ✓ | ✓ | ✓ | ✓ | ✓ | **✓** |
| Point-Cloud Projection/3D Mapping |  |  | ✓ |  |  | **✓** |

**Table 2**  
*Differentiation Table 2*

| Components | Viancy et al. (2024) | Hamilton-Fletcher & Arias (2021) | Han et al. (2025) | Commère & Rouat (2023) | Zhao et al. (2025) | World Navigation Hat  |
| :---- | ----- | ----- | ----- | ----- | ----- | ----- |
| Zero Form Single Board Computer | ✓ | ✓ | ✓ |  |  | **✓** |
| LiDAR Sensor |  | ✓ | ✓ | ✓ |  |  |
| Depth / RGB Camera | ✓ |  | ✓ |  |  | **✓** |
| IMU | ✓ | ✓ | ✓ |  |  | **✓** |
| Computer Vision / AI | ✓ | ✓ | ✓ | ✓ |  | **✓** |
| Audio Output (Earphones / Bone-Conduction) | ✓ | ✓ | ✓ | ✓ | ✓ | **✓** |
| Object Detection / Distance Estimation | ✓ | ✓ | ✓ | ✓ |  | **✓** |
| Mobile / Wearable Form | ✓ |  | ✓ | ✓ |  | **✓** |
| Point-Cloud Projection/3D Mapping |  | ✓ |  |  |  | **✓** |

**Table 3**  
*Prior Arts*

| Patent Title | Authors | Parameters | Publication No. | Publication Date |
| ----- | ----- | ----- | ----- | ----- |
| Stereo Vision-Based Sensory Substitution for the Visually Impaired | Simona Caraiman, Ovidiu Zagan | Stereo vision cameras, IMU integration, depth computation (Z \= 𝑓B/d), obstacle-to-audio/haptic mapping | PMC6630569 | June 20, 2019 |
| AI-Powered Smart Vision Glasses for the Visually Impaired | Devi Udayakumar, S. Gopalakrishnan | LiDAR, RGB camera, AI fusion, gesture/voice control, mobile app integration | PMC12178407 | May 30, 2025 |
| NIIRA: Non-Invasive Image Resynthesis into Audio (Sonic Vision for the Blind) | RealSense & Eyesynth Team | RealSense D415 camera, point-cloud depth mapping, SLAM, bone-conduction sound, obstacle detection up to 5 m | Intel RealSense Case Study | May 2025 |

# **Materials and Methods**

# **Research Design/Methods**

This research will follow a mixed-method design to develop, test, and analyze the results of the AIoT wearable navigation hat prototype for vision substitution, acting as an "artificial eye" for visually impaired users (e.g., fully blind, near-sighted, or partially sighted). The device uses a modular pipeline (stereo camera input to point cloud generation to virtual physical map to human vision emulation to audio cues) with toggleable hand gesture-controlled navigation, text/face recognition, and expense tracking. The study will employ a mixed-methods design, which will integrate a quantitative data collection and analysis of system performance metrics in terms of accuracy, speed, recall, and error rate derived from the device's functionality, with qualitative data collection and analysis of user experiences in terms of the device's performance, portability, and adaptability during device usage. As well as that, the quantitative findings for this research will be derived from the statistical analysis of data collected, including FPS, error percentages, success percentages, and route accuracies, and the qualitative insights will focus on the subjective user feedback on adaptation, ease of use, and overall comfort and performance in real-world scenarios of the device's functionality. In addition, in testing, there will be a within-subject experimental design and paired statistical testing (Paired T-Test), ensuring adequate power to detect significant differences between State A (continuous streaming of existing SSDs) and State B (research’s prototype, named Stesis, Selective Filtering). The functionality is prioritized in controlled/naturalistic settings, with p-values (e.g., t-tests, ANOVA at p \< 0.05) used to assess statistical significance, ensuring results are not due to chance. Utilizing the statistical tests, such as paired T-Test, P-Test, and ANOVA, assess reliability, and triangulation between methods validates findings, informing design refinements and potential clinical applications.

In addition, the researchers will use the Engineering Design Process (Figure 2\) to create a wearable navigation hat for visually impaired users. The goal is to ensure it meets VIPs needs while being comfortable and functional. The researchers will select key components and assemble them into a modular design, supported with clear diagrams and user-friendly models. Tailoring EDP, the navigation hat's prototyping method involves seven phases: 1\) identifying the problem and constraints, 2\) brainstorming possible solutions, 3\) selecting a solution and developing a design, 4\) building a prototype, 5\) evaluating the prototype, 6\) redesigning and optimizing prototype, and 7\) communicate results. This process focuses on creating practical and effective assistive devices tailored to users' needs and technical requirements.

[**Figure 2**](https://docs.google.com/document/d/1N4Ya048OJufQJaMhjFfynmU-Aq_rgIfC3wOmSFFCeBE/edit#figur_research)  
*Engineering Design Process (EDP) diagram of the Study*

1) ### **Identify the Problem and Constraints**

Identify the key problems and constraints VIP faces, including difficulties navigating their environment, safety risks, and cognitive overload from existing aids such as white canes and basic sound-sensing devices. Identify the needs for advanced technology that can effectively navigate and replicate human vision without requiring extensive user training. Establish the requirements for the hat and outline the project's necessary functions, including converting 3D environmental data into audio cues and ensuring portability through features such as battery power and ergonomic design. Constraints such as budget considerations, available components (e.g., the Raspberry Pi Zero 2W or other zero-form-factor single-board computers), and ethical guidelines (e.g., obtaining Institutional Review Board (IRB) approval). The focus remains on specific VIP challenges such as social isolation, navigation, mobility, and employment barriers, to align with evaluating AI frame rate (FPS) and user adaptation.

2) **Brainstorm Possible Solutions**

Illustrate various possible ideas for wearable designs, drawing inspiration from existing technologies such as Sound of Vision and Smart Hat. Consider emphasizing the use of IoT and AI for photogrammetry and inertial measurement units (IMUs), with a creative approach to enhance human senses and thereby reduce cognitive load. The goal is to connect physical and digital experiences to benefit a broader range of users.

3) ### **Select a Solution and Develop a Design**

Select the best design for implementation. This entails creating a detailed development plan that includes component selection, circuit diagrams, prototyping timelines, and considerations for ethical data collection and risk management. The prototype will focus on creating a wearable hat that integrates AIoT, providing audio cues while ensuring comfort and customizability for VIP users.

4) **Build a Prototype**

In the prototyping stage, the researchers will assemble the components according to specifications and conduct initial tests to verify functionality. Document the entire process, including any challenges faced, to streamline improvements. The development will focus on a user-friendly, efficient, ergonomically designed prototype for VIPs, integrating AIoT features for real-time feedback.

5) **Evaluate the Prototype**

A pilot test with 3 to 5 participants will be conducted before full implementation to evaluate device stability, safety, clarity of instructions, and environmental control. Adjustments identified during this phase will be made prior to the main experiment. Evaluation of the prototype involves conducting both quantitative and qualitative tests. This includes measuring AI FPS, depth accuracy, and other collected data, along with user trials to assess comfort and understanding. Feedback from focus groups and careful analysis of results will inform further refinements, helping identify and document any issues encountered during prototype testing.

6) ### **Redesign and Optimize**

Based on the feedback received, the prototype design will undergo iterative refinement. Changes may include enhancements to audio algorithms or modifications to extend battery life, ultimately striving to optimize the prototype for practical use by visually impaired individuals.

7) **Communicate Results** 

Shares the outcomes of prototyping and testing with key stakeholders. The outcome report comes with quantitative data on the accuracy of depth mapping, responsiveness of hand-gesture controls, AI processing speeds (FPS), and route-tracking precision, alongside qualitative feedback from user trials on comfort, ease of use, and system effectiveness. The researchers will communicate through clear reports, visualizations (e.g., graphs, tables, and 3D models), and demonstrations. 

# **Material and System Requirements**

The World Navigation Hat operates through a multi-stage processing pipeline that begins with data acquisition and culminates in audio feedback delivery. The Orange Pi Zero 2W microcontroller, powered by a 5V/3A UPS module, serves as the central processing unit that orchestrates all system operations. The process initiates with stereo image capture from dual OV5640 USB cameras positioned 12 cm apart, providing 5MP resolution at 160° field of view for photogrammetry operations. Concurrently, the MPU6050 Inertial Measurement Unit tracks head motion and orientation to align the virtual environment with the user's vestibular senses, preventing sensory conflicts. Audio input is captured through an earphone microphone for voice command recognition. Five primary applications run simultaneously on the device:

1. Photogrammetry processing that converts 2D stereo images into depth maps and 3D point clouds using stereo disparity calculations.  
2. Human visual sense emulation pipeline that implements foveation, selective attention, and scene gist extraction to generate necessary audio cues while minimizing cognitive overload.  
3. MediaPipe AI for real-time hand gesture recognition enabling touchless device control.  
4. Modular framework allowing custom applications to integrate into the main pipeline with connection to the main server through standard APIs.  
5. Processed data transmitted via the WiFi to a NodeJS server infrastructure that handles additional computational tasks including external API integration, SQL database management, and HTTP server operations for client-server communication.

**Hardware Materials**  
The hardware architecture integrates several critical components optimized for portable wearable computing. 

The Orange Pi Zero 2W single-board computer features a quad-core ARM Cortex-A53 processor with 512MB/1GB RAM options, providing sufficient computational power for real-time computer vision tasks while maintaining low power consumption suitable for battery operation. 

Two OV5640 USB cameras serve as the stereo vision system, each delivering 5-megapixel resolution with a 160° field of view and positioned with a 10 cm baseline to enable accurate depth estimation through stereo disparity calculations. 

The MPU6050 6-axis Inertial Measurement Unit combines a 3-axis gyroscope and 3-axis accelerometer, providing motion tracking data at high refresh rates to synchronize the virtual environment with user head movements. 

The Orange Pi Extension Board’s audio module facilitates bidirectional audio communication, connecting both speaker output for audio cues and microphone input for voice commands through standard 3.5mm earphone jacks.

Power management is handled by a custom UPS module accepting 5V/3A input, featuring lithium battery charging circuits (supporting 18650 or similar rechargeable cells) and voltage regulation to ensure stable operation during mobile use. 

All components are mounted on a 3D custom-designed hat frame measuring 333.38 mm in length with integrated cable management and component housings to maintain ergonomic comfort during extended wear.

**Software Specifications**

The software ecosystem operates across two primary environments: client-side processing on the Orange Pi Zero 2W and server-side operations on a NodeJS platform. 

The client-side implementation utilizes Python 3.x as the primary programming language, leveraging OpenCV (cv2) for image acquisition, preprocessing, and stereo vision algorithms including stereo calibration, rectification, and disparity map generation.

NumPy provides optimized numerical computing for point cloud transformations, matrix operations in photogrammetry calculations (applying the stereo projection matrix Q to depth maps), and efficient array manipulations for real-time processing.

Matplotlib enables visualization during development and debugging phases, generating spectrograms for audio cue analysis and 3D scatter plots for point cloud verification. 

MediaPipe framework implements hand gesture recognition through pre-trained machine learning models optimized for mobile deployment, detecting key hand landmarks and classifying gestures with minimal latency. 

PyTorch serves as the deep learning backend for custom neural network implementations, including depth estimation refinement models and audio generation networks that emulate human auditory processing. 

Additional Python libraries include SciPy for signal processing (audio synthesis, filtering), librosa for audio feature extraction, and pyserial for communication with peripheral modules (MPU6050). 

The server-side infrastructure runs NodeJS with Express framework for HTTP server operations, handling REST API endpoints for client requests, managing WebSocket connections for real-time bidirectional communication, and coordinating database operations through SQL query execution. 

The development workflow integrates multiple productivity and collaboration tools to streamline project organization, documentation, and version control. 

Visual Studio Code (VSCode) serves as the primary integrated development environment (IDE), providing syntax highlighting for Python and JavaScript, integrated terminal access for remote SSH connections to the Orange Pi Zero 2W, Git integration for version control operations, and extensive extension support including Python linters (pylint, flake8), formatters (black, autopep8), and remote development extensions for direct editing on embedded systems. 

GitHub hosts the project repositories, implementing version control through Git for both client-side Python applications and server-side NodeJS code, facilitating collaborative development among team members through branch management, pull requests, code reviews, and issue tracking for bug reports and feature requests. 

LaTeX document preparation system generates the formal thesis documentation with precise mathematical typesetting for equations including stereo disparity formulas, point cloud projection matrices, and depth-to-audio mapping functions, ensuring professional formatting standards for academic submission while maintaining version-controlled .tex source files. 

Google Docs provides real-time collaborative editing for preliminary research documentation, literature review organization, meeting notes, and draft content development, enabling simultaneous multi-user editing with comment threads for peer feedback and revision tracking. 

Microsoft Office suite (Word, Excel, PowerPoint) supports supplementary documentation tasks including formatted research proposals, data analysis spreadsheets for experimental results (accuracy measurements, user feedback surveys, performance benchmarks), and presentation materials for design reviews and project demonstrations. 

Claude AI assists throughout the development lifecycle as an AI-powered coding assistant and research tool, providing algorithm optimization suggestions, debugging support for complex stereo vision calculations, documentation generation for API endpoints and function specifications, literature synthesis for theoretical framework development, and technical writing refinement for thesis chapters. 

SolidWorks is CAD software used to create 3D models and conduct simulations in engineering and manufacturing. The software is used to create the 3D design of the navigation hat's prototype device system.

KiCad is a free, open-source tool for designing electronic circuits and PCBs. The software application is used to design and simulate the schematics that connect various components for the navigation hat project. 

This integrated software toolchain ensures systematic project management from initial concept through final implementation, maintaining code quality through version control, facilitating team collaboration across distributed work environments, and producing comprehensive documentation that meets both academic standards and technical reproducibility requirements.

**Library and Board Managers**  
Development and deployment require specific software dependencies managed through multiple package systems across different platforms. For the Orange Pi Zero 2W running Armbian or Ubuntu-based distributions, the APT package manager handles system-level dependencies including Python 3.x development packages (python3-dev, python3-pip), OpenCV system libraries (libopencv-dev, python3-opencv), audio system requirements (libasound2-dev, portaudio19-dev), and USB camera support utilities (v4l-utils). Python package management through pip3 installs critical libraries with specific version constraints: opencv-python (≥ 4.5.0) for computer vision operations, numpy (≥ 1.21.0) for numerical computing, mediapipe (≥ 0.8.0) for hand tracking AI models, torch (≥ 1.10.0) with ARM-compatible builds for deep learning inference, sounddevice and soundfile for audio I/O operations, pyserial (≥ 3.5) for hardware communication, and requests for HTTP client functionality. Arduino IDE or Platform IO manages firmware for any auxiliary microcontrollers if implemented, including board definitions for custom boards and library dependencies for sensor communication protocols (I2C for MPU6050, SPI for peripheral modules). The NodeJS ecosystem uses npm (Node Package Manager) to install server-side dependencies: express (≥ 4.18.0) for web server framework, ws for WebSocket implementation, sequelize or knex for SQL database ORM, axios for HTTP client operations to external APIs, and child\\\_process management for spawning Ollama and YOLO processes. Board-specific configurations require Orange Pi GPIO libraries (OrangePi.GPIO or wiringOP) for direct hardware pin control if needed, and kernel module loading for camera interfaces (ensuring proper v4l2 driver support for OV5640 USB cameras through modprobe configurations). Git version control manages source code across development iterations, with repositories configured for both client and server codebases, while systemd service configurations enable automatic startup of critical applications on boot for production deployment.

### **Other Materials/Equipment/Devices**

Beyond the core electronic components, the project requires supplementary materials and equipment for fabrication, testing, and evaluation. The physical enclosure utilizes 3D-printed components designed in CAD software, with wireframe dimensions of 333.38 mm length, 197.50 mm width, and component-specific mounting features including camera housings with 12 cm spacing alignment, ventilated sections for heat dissipation from processing components, and cable routing channels. The 3D printing process uses PLA filament for structural components requiring strength and thermal stability, with print settings optimized for layer adhesion and surface finish to ensure user comfort during extended wear. A standard baseball cap or adjustable hat frame serves as the foundation for component integration, providing familiar ergonomics and adjustable sizing through standard strap mechanisms. Micro SD card (minimum 32GB Class 10 or UHS-I) stores the operating system, application code, and temporary data cache for the Orange Pi Zero 2W. Lithium-ion battery cells (18650 format, 3.7V nominal, minimum 2500mAh capacity) power the UPS module, with appropriate battery holders and spot-welded connections ensuring reliable electrical contact and mechanical stability. USB-C cable provides a charging interface for the UPS module, allowing users to recharge using standard mobile phone chargers or power banks. Testing and evaluation equipment includes a reference measuring device (laser rangefinder or calibrated ruler) for depth accuracy validation, comparing predicted distances from stereo disparity calculations against ground truth measurements across various ranges (0.5m to 5m typical operating distance). A standardized navigation course with marked obstacles, varying textures, and elevation changes facilitates user testing protocols for evaluating device effectiveness. Audio analysis equipment (reference microphone, audio interface, spectrum analyzer software) characterizes the generated audio cues for frequency response, dynamic range, and spatial positioning accuracy. Additionally, development workstations (laptop/desktop computers with Linux or Windows OS) run cross-compilation toolchains, debugging interfaces (SSH, serial console), and simulation environments for algorithm validation before hardware deployment. Safety equipment for user testing includes protective padding for obstacle courses, first aid supplies, and emergency communication devices in compliance with IRB-approved testing protocols outlined in the ethical considerations section.

# **Prototype Building**

[**Figure 3**](https://docs.google.com/document/d/1N4Ya048OJufQJaMhjFfynmU-Aq_rgIfC3wOmSFFCeBE/edit#figur_block)  
*Block diagram of the System*

[Figure 3](https://docs.google.com/document/d/1N4Ya048OJufQJaMhjFfynmU-Aq_rgIfC3wOmSFFCeBE/edit#fig_block) illustrates the simplified hardware-software interaction flow of the World Navigation Hat system, showing the essential component connections and data pathways. The architecture begins with power distribution from a 5V Lithium Battery that feeds into the UPS Module (5V/3A), which provides regulated power (indicated by a lightning bolt symbol) to the central Microcontroller (Orange Pi Zero 2W or similar embedded system). Multiple input sensors connect directly to the microcontroller: the Digital Camera (OV5640) captures stereo visual data for photogrammetry and depth mapping, the IMU (MPU6050) provides 6-axis motion tracking data for head orientation and movement detection. The microcontroller outputs audio feedback through the Speaker, delivering spatial audio cues that convey environmental information to the visually impaired user. Bidirectional communication flows between the microcontroller and the SIM and GPS Module, which provides both GPS positioning data for outdoor navigation and wireless connectivity options (WiFi or Mobile Data, indicated by wireless symbols) to enable internet access. This connectivity links the device to a remote Server (NodeJS), which hosts computationally intensive processes like Local AI models and facilitates integration with External APIs, all of these are mock APIs has actually implementing the applications is the role of the third party developers and not necessary to prove our hypothesis. The server acts as the computational backbone for tasks beyond the microcontroller's capacity, processing complex AI inference requests and coordinating with cloud services, while the embedded system handles real-time sensor fusion, basic computer vision operations, and immediate audio feedback generation—creating a distributed computing architecture that balances on-device responsiveness with cloud-enhanced intelligence for comprehensive assistive navigation capabilities.  
[**Figure 4**](https://docs.google.com/document/d/1N4Ya048OJufQJaMhjFfynmU-Aq_rgIfC3wOmSFFCeBE/edit#figur_architecture)  
*System Architecture* 

Figure 4 illustrates the system architecture diagram of the complete data flow and component interaction of the World Navigation Hat, showing how sensory input is processed and transformed into actionable navigation assistance for visually impaired users. The process begins with three primary sensor categories: the dual OV5640 cameras (5MP at 160° FOV, spaced 10 cm apart) capture stereo images for photogrammetry, the Inertial Measurement Unit (IMU) tracks head motion and orientation. These inputs feed into the Orange Pi Zero 2W microcontroller, which runs four core applications concurrently: (1) Emulated Vision to Audio—converting stereo images into 3D point clouds and depth maps, then applying human visual processing emulation (foveation, selective attention, scene gist extraction) to generate spatially-aware audio cues delivered through the earphone speaker; (2) Photogrammetry—reconstructing 3D environmental geometry from stereo disparity calculations; (3) Hand Gesture Recognition via MediaPipe AI—detecting user hand gestures for touchless device control and parameter adjustment; and (4) Server API integration—connecting to external computational resources. Data flows bidirectionally between the Orange Pi Zero 2W and a central server platform, where NodeJS processes coordinate with external APIs (e.g. Google Maps, Meta platforms) to enhance navigation capabilities. The server infrastructure manages three interconnected virtual map representations: the Virtual Physical Map derived from real-time photogrammetry and GPS positioning showing the user's immediate surroundings with obstacle locations, the Virtual Digital Map providing access to online navigation services and digital content, and a unified spatial model that bridges physical and digital navigation contexts. Throughout this pipeline, the IMU continuously synchronizes the virtual environment with the user's head movements to maintain vestibular alignment and prevent disorientation, while the modular architecture allows applications to access any stage of the processing pipeline—enabling customization for specific user needs such as text reading, face recognition, or expense tracking—all working cohesively to transform complex visual-spatial information into intuitive, non-overwhelming audio feedback that empowers independent navigation for visually impaired individuals.  
[**Figure 5**](https://docs.google.com/document/d/1N4Ya048OJufQJaMhjFfynmU-Aq_rgIfC3wOmSFFCeBE/edit#figur_3d)  
*3D Model Design of the Prototype*  
Figure 5 is the 3D CAD rendered model of the prototype that shows the physical appearance of the World Navigation Hat's core electronics enclosure, designed as a compact, wearable sensory substitution device for visually impaired individuals. The cylindrical housing features a removable top lid embossed with a stylized logo, revealing the internal Orange Pi Zero 2W single-board computer (shown in green PCB with the prominent blue Allwinner H618 processor) mounted on a platform with ventilation holes for heat dissipation during intensive AI processing tasks. The device integrates into a modified hat brim structure (visible as the curved frame at the base) with attachment points and cable routing channels that secure cameras, sensors, and the UPS battery module while maintaining ergonomic comfort for extended wear. Small external ports (visible on the lower left) provide access for USB charging, while the sealed design protects sensitive electronics from environmental elements during outdoor navigation, embodying the project's goal of transforming bulky assistive technology into an unobtrusive, socially acceptable wearable that converts real-time visual information into intuitive audio cues through advanced photogrammetry, AI-driven scene understanding, and human sensory process emulation.

[**Figure **](https://docs.google.com/document/d/1N4Ya048OJufQJaMhjFfynmU-Aq_rgIfC3wOmSFFCeBE/edit#figur_wireframe)**6**  
*Wireframe of the Device*

[**Figure**](https://docs.google.com/document/d/1N4Ya048OJufQJaMhjFfynmU-Aq_rgIfC3wOmSFFCeBE/edit#figur_measurement) **7**  
*Measurement of the Prototype*

| A: Hat top diameter  B: Total height  C: Camera distance D: Hat Trim diameter  E: Hat Brim diameter  F: Hat Sweatband diameter  G: Wire clamp outer length  H: Strap handle outer length  I: Earphone wire channel radius  | J: Strap handle inner length K: Wire clamp width L: Wire clamp inner length M: Camera height \- from bottom of hat N: Total height \- without strap handle O: Cover diameter P: Antenna hole position \- relative to hat Q: Antenna hole diameter |
| :---- | :---- |

[**Figure**](https://docs.google.com/document/d/1N4Ya048OJufQJaMhjFfynmU-Aq_rgIfC3wOmSFFCeBE/edit#figur_circuit) **8**  
*Complete Circuit Diagram of the System*  
![][image1]  
[Figure ](https://docs.google.com/document/d/1N4Ya048OJufQJaMhjFfynmU-Aq_rgIfC3wOmSFFCeBE/edit#fig_circuit)8 illustrates the complete hardware interconnection architecture of the World Navigation Hat system, showing how all components integrate to form a functional wearable assistive device for visually impaired individuals.  
**Power Distribution System**  
The USB-C 5V/3A UPS Module serves as the primary power source, positioned at the bottom of the diagram with a yellow arrow indicating the external power input connection. This rechargeable power management unit supplies regulated 5V power to all system components, with Chinese text indicating battery charging specifications and protection circuitry. The green PCB features multiple power regulation stages with visible inductors (marked as 74Z), capacitors (both electrolytic and ceramic), and battery management ICs to ensure stable operation during mobile use and support lithium battery charging cycles. Power consumption and battery life calculations of the system device: 

1) Battery Energy Calculation

		Formula: Ebatt \= Qbatt × 2 ×Vbatt1000  
Qbatt \= 3600 mAh (capacity of one battery, doubled for two batteries)  
Vbatt \= 3.7 V  
		Solving:   
Ebatt \= 3600mAh × 2 × 3.7V1000 \= 26\. 64 Wh

2) Component Power Calculations  
   	2.a) Orange Pi  
   		Ppi-idle ≈ 1.09W 

   Ppi-active ≈ 2.4W 

   Ipi-peak \= 2A   
   Vpi \= 5V  
   	Ppi-idle \= 1.09W   
   Ppi-active \= 2.4W

   2.b) OV5640  
   		I5640-sleep \= 20𝜇A

   I5640-active \= 140mA   
   V5640 \= 3.3V

   Sleep:

   P5640-sleep \= I5640-sleep  V5640 \= 20𝜇A × 3.3V \= 66𝜇W \= 0.000066 W

   Active: 

   P5640-active \= I5640-active  V5640 \= 140mA × 3.3V \= 462mW   
   	   \= 0.462 W

   2\. c) Earphones

   Iearph ≈ 19.02mA   
   Vearph ≈ 0.21V  
   Pearph \= Iearph  Vearph \= 19.02mA × 0.21V ≈ 4mW \= 0.004 W  
     
3) Total System Power (Accounting for UPS Efficiency, (η\_ups) is 85% (0.85))

   Formula: Ptotal-mode \= Pcomponentsη\_ups

   Sleep Mode: 

   	Ptotal-sleep \= Ppi-idle \+ P5640-sleep \+ Pearphη\_ups

   		 \= 1.09 \+ 0.000066 \+0.00485%

   		 \= 1.094066 85%

   		 \= 1.2871364W ≈ 1.3W

   Active Mode:

   		Ptotal-sleep \= Ppi-active \+ P5640-active \+ Pearphη\_ups

   			 \= 2.4 \+ 0.462 \+0.00485%

   			 \= 2.866 85%

   			 \= 3.37 W 

4) Battery Life Calculation

		Formula: Tmode \= EbattPtotal-mode  
		Sleep Mode:   
				Tmode \= EbattPtotal-sleep \= 26.641.3 \= 20.4923077 h ≈ 20.49 h  
		Active Mode:  
				Tmode \= EbattPtotal-active \= 26.643.37 \= 7.9 h   
Therefore, the device can run approximately 20.49 hours in sleep mode and 7.9 hours in active mode, based on the battery capacity and calculated power draws. 

**Central Processing Unit**  
The Orange Pi Zero 2W single-board computer occupies the central position in the architecture, acting as the main computational hub. It features the Allwinner H618 quad-core processor (visible as the large silver chip), USB ports for camera connectivity, a micro-SD card slot for operating system and data storage, GPIO header pins for peripheral connections, and HDMI output. The board receives 5V power from the UPS module (indicated by red power lines) and ground connections (black lines), while managing bidirectional data communication with all sensors and actuators.

**Stereo Vision System**  
Two OV5640 USB Cameras are positioned at the top right of the Figure 8 diagram, each providing 5MP resolution at 160° field of view. These cameras are mounted with a precise 12 cm baseline separation (as noted in the physical prototype specifications) and connect to the Orange Pi Zero 2W via USB interfaces (shown by thick black connection lines). The stereo camera configuration enables depth perception through stereo disparity calculations, capturing simultaneous images from slightly different viewpoints to generate data essential for environmental mapping and obstacle detection.

**Motion Sensing**

The MPU6050 Inertial Measurement Unit (6-axis gyroscope and accelerometer) appears as a small blue module at the center-top of the Figure 8 diagram. It connects to the Orange Pi Zero 2W through I2C communication protocol (indicated by green connection lines labeled with I2C pins: SCL, SDA, VCC, GND). This sensor tracks head motion and orientation in real-time, providing critical data for aligning the virtual environment representation with the user's physical movements, preventing vestibular-visual conflicts that could cause disorientation or nausea.

**Audio Interface**  
The Orange Pi Extension Board V1.0 includes a 3.5mm jack supporting both audio output and microphone input through a single connector. The earphone illustration at the Figure 8 shows standard earbud-style output for delivering spatial audio cues to the user.

**Connection Architecture**  
Color-coded wiring illustrates the data flow and power distribution:

* Red lines: 5V power rails from UPS to all components  
* Black lines: Ground connections ensuring common reference voltage.  
* Green lines: I2C communication (MPU6050), or other digital communication protocols.  
* Thick black lines: USB data connections for high-bandwidth camera feeds.

**Physical Integration**  
All components are designed to mount within the 3D-printed hat enclosure shown in previous wireframe diagrams, with the UPS module likely positioned at the rear for weight distribution, the Orange Pi Zero 2W in the central crown area for protection, cameras mounted at the front brim for unobstructed field of view, and the IMU positioned near the cameras to accurately track head orientation relative to the visual input direction. The compact arrangement maintains the wearable form factor while ensuring proper thermal management through ventilation and component spacing.

[**Figure 9**](https://docs.google.com/document/d/1N4Ya048OJufQJaMhjFfynmU-Aq_rgIfC3wOmSFFCeBE/edit#figur_schematic)  
*Complete Schematic Diagram of the System*

Figure 9 illustrates the schematic diagram of the entire system, showing the layout of the power, sensor, processing, communication, and audio modules, along with their interconnections, that form the wearable navigation hat system. The power system of the device is the battery (BT1) that powers the system via an uninterruptible power supply (UPS1), distributing stable power to the Orange Pi Zero 2W and other components. The main processing unit is the Orange Pi Zero 2W that serves as the central controller, interfacing with two USB cameras for stereo image capture and 3D reconstruction. The sensor modules that are connected to the Orange Pi are the MPU-6050 IMU via I2C or motion tracking. The audio output for the navigation cues is delivered through the TRRS bus to an earphone (LS1), with resistors for signal integrity and volume control. The system includes integrated earth and ground points to ensure stable reference voltages and minimize noise.

[**Figure 10**](https://docs.google.com/document/d/1N4Ya048OJufQJaMhjFfynmU-Aq_rgIfC3wOmSFFCeBE/edit#figur_cam1)  
*OV5640 Camera Schematic Diagram*

Figure 10 shows the schematic diagram of the USB camera interface (DVP-USB1) connected to the camera module (OV5640-DVP1) for your wearable navigation hat system. The DVP-USB1 captures data from the USB camera. It provides power (USB-VCC), ground (USB-GND), data lines (USB-Data+ and USB-Data–), pixel data signals (Y0-Y9), and clock/control signals (PCLK, VSYNC, HREF, XCLK, SIO\_CLK, SIO\_DAT, PWDN, RESET). The OV5640-DVP1 receives these signals with matching pins for pixel data, grounds (AGND and DGND), and power supplies (AVDD, DVDD, DOVDD). Each pin from DVP-USB1 connects directly to the corresponding pin in OV5640-DVP1. It supports real-time stereo image acquisition and helps create depth maps for the navigation hat system.

[**Figure 11**](https://docs.google.com/document/d/1N4Ya048OJufQJaMhjFfynmU-Aq_rgIfC3wOmSFFCeBE/edit#figur_cam2)  
*Component Diagram Orange Pi Expansion Board to Orange Pi Zero 2W*

**Table 4**  
*Pin Configuration of Orange Pi Expansion Board to Orange Pi Zero 2W*

| Wire/Cable | From (Expansion Board USB) | To (DVP-to-USB Bridge) | Function |
| :---- | :---- | :---- | :---- |
| Blue Trace 1 | USB 5V | 5V | Power Supply |
| Blue Trace 2 | USB D- | D- | USB Data \- |
| Blue Trace 3 | USB D+ | D+ | USB Data \+ |
| Blue Trace 4 | USB GND | GND | Ground |

Figure 11 and Table 1 illustrate the Orange Pi Zero 2W connects to the Orange Pi Expansion Board through a single flexible 24-pin FPC ribbon cable that links the matching 24-pin interfaces on both devices. This connection carries all essential signals including power lines, GPIO controls, and communication buses such as I2C, SPI, and UART from the Zero 2W’s processor to the Expansion Board. By relaying these signals, the Expansion Board expands the capabilities of the compact Zero 2W, providing access to additional peripherals such as full-sized USB ports, an RJ45 Ethernet jack, and an audio jack, thereby enhancing the system’s overall functionality.  
[**Figure 1**](https://docs.google.com/document/d/1N4Ya048OJufQJaMhjFfynmU-Aq_rgIfC3wOmSFFCeBE/edit#figur_cam2)**2**  
*Component Diagram UPS Module to Orange Pi Orange Pi Zero 2W*

**Table 5**  
*Pin Configuration of UPS Module to Orange Pi Orange Pi Zero 2W*

| Wire Color | From (UPS Module) | To (Orange Pi Zero 2W) | Function |
| :---- | :---- | :---- | :---- |
| Red | UPS+ (Top Right Pad) | Pin 2 (Physical Pin 2\) | \+5V Power Input |
| Black | \-UPS (Bottom Right Pad) | Pin 6 (Physical Pin 6\) | Ground (GND) |

Figure 12 and Table 2 illustrate the power system is designed as a battery-centric Uninterruptible Power Supply (UPS) using an 18650 5V/3A UPS Module and two 18650 batteries to power the device. The Orange Pi Zero 2W receives its 5V operating voltage directly from the UPS module’s output terminals, with the 5V+ terminal (red wire) connected to the 5V pin on the Orange Pi’s GPIO header and the 5V– terminal (black wire) connected to a GND pin. The UPS module draws energy from the batteries, regulates it to a stable 5V, and supplies it to the Orange Pi Zero 2W, ensuring continuous operation even if the external power source is disrupted, thereby providing true uninterruptible power capability.

[**Figure 1**](https://docs.google.com/document/d/1N4Ya048OJufQJaMhjFfynmU-Aq_rgIfC3wOmSFFCeBE/edit#figur_cam2)**3**  
*Component Diagram Earphones to Orange Pi Orange Pi Zero 2W*

**Table 6**  
*Pin Configuration of Earphones to Orange Pi Orange Pi Zero 2W*

| Component | Connected To | Description |
| :---- | :---- | :---- |
| 3.5mm Earphones | Expansion Board Audio Jack | Standard analog audio output for music or system sounds. |

Figure 13 and Table 3 illustrate the audio output capability of the system is realized by connecting standard earphones directly to the Orange Pi Expansion Board. The earphones connect to the Orange Pi Expansion Board through a standard 3.5mm audio jack, receiving an audio signal that originates from the Orange Pi Zero 2W, travels through the 24-pin FPC interface to the Expansion Board, and is routed to the audio jack circuitry, allowing users to listen to audio playback directly from the system.  
[**Figure 1**](https://docs.google.com/document/d/1N4Ya048OJufQJaMhjFfynmU-Aq_rgIfC3wOmSFFCeBE/edit#figur_cam2)**4**  
*Component Diagram Orange Pi Expansion Board to Camera OV5640*

**Table 7**  
*Pin Configuration Orange Pi Expansion Board to Camera OV5640*

| Wire/Cable | From (DVP-to-USB Bridge) | To (OV5640 Camera) | Function |
| :---- | :---- | :---- | :---- |
| Ribbon Cable | FPC Connector | FPC Connector | DVP Interface (Video Data) |

\`	Figure 15 and Table 5 illustrate the system connects two OV5640 Camera Modules to the Orange Pi Expansion Board using a chain of components. The dual camera setup connects two OV5640 camera modules to a 2-channel DVP-to-USB bridge board, which converts their video signals into a single USB output. This USB output is then linked to one of the USB ports on the Orange Pi Expansion Board using a ribbon cable. From there, the video data travels through the Expansion Board, which is connected to the Orange Pi Zero 2W via a 24-pin FPC cable, allowing the Expansion Board to act as a hub that passes the combined USB video stream into the Zero 2W for processing. This arrangement enables the Orange Pi Zero 2W to handle dual OV5640 camera feeds through its extended USB interface, making it suitable for applications like stereo vision or multi-angle imaging.  
[**Figure 1**](https://docs.google.com/document/d/1N4Ya048OJufQJaMhjFfynmU-Aq_rgIfC3wOmSFFCeBE/edit#figur_cam2)**5**  
*Component Diagram MPU9250 to Orange Pi Zero 2W*

**Table 8**  
*Pin Configuration MPU9250 to Orange Pi Zero 2W*

| Wire Color | From (MPU9250) | To (Orange Pi Zero 2W) | Function |
| :---- | :---- | :---- | :---- |
| Red | VCC | Pin 1 | 3.3V Power |
| Blue | SDA | Pin 3 | I2C SDA (Data) |
| Blue | SCL | Pin 5 | I2C SCL (Clock) |
| Black | GND | Pin 9 | Ground (GND) |

Figure 16 and Table 6 illustrate that the MPU9250 Inertial Measurement Unit (IMU) connects to the Orange Pi Zero 2W using four wires through the GPIO header and the I2C interface. Two wires are for communication: a black wire connects the SCL pin of the MPU9250 to the I2C Clock pin on the Orange Pi, while a blue wire connects the SDA pin to the I2C Data pin. For power, a red wire connects the MPU9250's VCC pin to the Orange Pi's 3.3V pin, and a black wire connects the GND pin to a ground pin on the Orange Pi.

[**Figure 1**](https://docs.google.com/document/d/1N4Ya048OJufQJaMhjFfynmU-Aq_rgIfC3wOmSFFCeBE/edit#figur_flow)**6**  
*Flowchart of the Three Main Pipelines*

The flowchart at [Figure 12](https://docs.google.com/document/d/1N4Ya048OJufQJaMhjFfynmU-Aq_rgIfC3wOmSFFCeBE/edit#fig_flow) illustrates the modular software architecture of the World Navigation Hat, organized into three concurrent processing pipelines that work together to provide comprehensive assistive navigation through sensory substitution. The Main Pipeline forms the core sensory substitution system, beginning with "Two images from stereo cameras" captured simultaneously from the dual OV5640 cameras positioned 10 cm apart, which undergo photogrammetry processing by applying stereo disparity calculations (Z \= f·B/d) that create a three-dimensional representation of the environment where each pixel's depth is computed and transformed into 3D spatial coordinates; this point cloud data is then used to "Record to virtual environment," creating a persistent spatial map integrated with IMU-tracked head movements to form a coherent representation of the user's surroundings. The Gesture Pipeline runs in parallel, providing touchless user control through "Scan for hand gesture" using MediaPipe AI models that continuously analyze camera frames to detect hand landmarks—when a gesture is detected, the system evaluates "Gesture matches an instruction?" and if true, proceeds to "Update mode of expression," modifying parameters that affect how the Main Pipeline generates audio output (allowing users to switch between obstacle detection, text reading, or face recognition modes), then checks "Instruction requires Services?" to determine whether the command needs server-side processing, branching to the Server Pipeline if yes or merging directly back to the Main Pipeline if no. The Server Pipeline handles computationally intensive tasks, where requests are transmitted via the WiFi to the NodeJS platform, which may invoke external APIs, then proceeds to "Read response" to collect and format results before "Add to output audio" packages the server-processed information and transmits it back to merge with the Gesture Pipeline. All three pipelines converge through diamond-shaped merge points before the final stage where the system "Generate audio based on mode of expression," transforming consolidated environmental data, user control inputs, and cloud-enhanced intelligence into spatial audio cues through algorithms that emulate human visual processing—implementing foveation (focus-based detail levels), selective attention (filtering salient features), scene gist extraction (background/foreground separation), and temporal dynamics (progressive audio updates)—before finally proceeding to "Output audio to earphones," delivering intuitive sonic representations that respect cognitive load limitations while maximizing navigational utility, embodying the research's core innovation of solving the bandwidth mismatch between high-detail visual information and lower-bandwidth auditory perception.

# **Data Presentation & Analysis**

In this study, the researchers will use specific formulas and statistical tools to quantify the system's depth conversion, precision, and gesture detection. Furthermore, the metrics will be used by the researchers to assess the navigation hat's performance in converting stereo camera inputs into audio cues for navigation. The results will be analyzed and displayed by two categories: 1\) Quantitative Data Presentation and Analysis, and 2\) Qualitative Data Presentation and Analysis. 

1\) Quantitative Data Presentation and Analysis 

The results will be displayed through descriptive statistics such as means and standard deviations, inferential tests (specifically t-tests with p-values), and visual aids such as charts. The analysis will emphasize the statistical significance (p \< 0.05) to discern meaningful trends, using software such as Python for reliability checks and cross-validation.

1.a) Photogrammetry Performance: The data presentation includes tables of error metrics and success rates by environment, alongside scatter plots for regression analysis. The statistical tests, paired t-tests will reveal the differences in accuracy.

Formula References:

1.a.1) Percentage Error Formula- Expresses the error between a measured value and the true value (e.g., predicted vs. actual direction or depth).

1.a.2) Success Percentage Formula- Measures the proportion of successful trials (e.g., correct predictions by user or device).

1.a.3) Stereo Camera Matrices \- Intrinsic and extrinsic representation of left *(C1)* and right *(C2)* cameras,where *f* is focal length in pixels, *cx, cy* are principal point coordinates, and *Tx* is the baseline. 

1.a.4) Stereo Reprojection Matrix *(Q)* \-Use to compute 3D points from disparity: convert (*x, y* disparity) into 3D coordinates.

1.a.5) Point Cloud Projection Formula \- Reprojects a pixel with disparity into 3D space using the *Q* matrix.

**Table 9**  
*Photogrammetry Performance Metrics*

| Environment | Mean Percentage Error (%) ± SD | Success Percentage (%) | t-test p-value  (vs. Ground Truth) |
| ----- | ----- | ----- | ----- |
| Indoor  |  |  |  |
| Outdoor  |  |  |  |
| Average |  |  |  |

Table 7 compares the mean percentage error, success percentage, and t-test p-values for depth mapping accuracy in indoor and outdoor environments, highlighting environmental impacts on the navigation hat's 3D reconstruction.

1.b) **Gesture Command Responsiveness:** Data will be presented in confusion matrices and metric tables, with binomial tests used to evaluate proportions. Whereas,

* TP (True Positive) stands as a "correct yes." For example, if the user does a thumbs-up gesture and the hat correctly switches to navigation mode. It means the hat got it right when it should have acted.   
* FP (False Positive): This is the "wrong yes." If the hat thinks the user did a thumb-up (and switches modes) but did not actually do the gesture, that is an FP. It is like a false alarm—the hat acted when it should not have.   
* TN (True Negative): The "correct no." If the user does not do any gestures and the hat stays put correctly (no mode switch), that is a TN. It means the hat did not react when it should not have.   
* FN (False Negative): A "wrong no". The user does a gesture, but the hat misses it and does not switch. These help calculate accuracy: more TP/TN means the hat is reliable.  
  1.b.1) Precision: Correctness of detections. Formula: TP / (TP \+ FP).   
  1.b.2) Recall: Completeness of detections. Formula: TP / (TP \+ FN).   
  1.2.c) Accuracy: Overall performance. Formula: (TP \+ TN) / Total.

**Table 10**  
*Gesture Command Responsiveness Metrics*

| Gesture | TP | FP | FN | TN | Precision | Recall | Accuracy |
| ----- | ----- | ----- | ----- | ----- | ----- | ----- | ----- |
| Thumbs Up |  |  |  |  |  |  |  |
| Pointing Index |  |  |  |  |  |  |  |
| Open Back Hand |  |  |  |  |  |  |  |
| Close Back Hand |  |  |  |  |  |  |  |
| Average |  |  |  |  |  |  |  |

Table 8 shows the confusion matrix values of classification outcomes of hand gestures (TP, FP, FN, TN) for the navigation hat, illustrating how well it detects hand commands for mode toggling. The table also summarizes the precision, recall, and accuracy for each gesture type, with ANOVA p-values indicating variations in responsiveness across modes.

1.c) **Modular AI and GPS Performance**: Tests how well the navigation hat's built-in AI (for recognizing objects or faces) and GPS (for tracking location) work together. It is like checking whether the hat can quickly spot items and guide the user accurately as they move.  
1.c.1) Tables and graphs depict FPS trends and errors: The researchers will use charts to show how fast the hat processes data (FPS) over time and any mistakes (errors). Regression is a math trick for determining whether one thing (like speed) relates to another (like errors).  
1.c.2) Mean FPS ± SD: The average speed of the hat's processing (frames per second, like video frames). The formula sums all speeds and divides by the number of tests, with SD indicating how much it varies. Example: For speeds of 18, 19, and 18.5, the average is 18.5, and the SD of 0.5 means it is pretty consistent.  
Formula: 

* Processing speed: FPSn  
* SD for variability: (FPSi-Mean)2n-1  
  1.c.3) Error Rate: How often the AI gets incorrect (e.g., mistaking an object). Example: 2 mistakes out of 100 tests \= 2% error rate.

  Formula: FP+FNTotal× 100

  1.c.4) Route MAE: For GPS, the average distance the hat's location guess is off from the real spot (in meters). Example: Errors of 1.0, 1.5 and 1.2 meters average to 1.23 meters.  
  Formula: |errors|n

**Table 11**  
*Modular System AI Processing and Route Accuracy Metrics*

| Module | Mean FPS ± SD | Error Rate (%) | Route MAE (m) ± SD | t-test p-value (Pre/Post-Toggle) |
| :---- | ----- | ----- | ----- | ----- |
| Object Recognition |  |  |  |  |
| Face Recognition |  |  |  |  |
| Text Recognition |  |  |  |  |
| GPS Tracking |  |  |  |  |
| Average |  |  |  |  |

Table 9 presents the mean FPS, error rates, route MAE, and t-test p-values for AI modules and GPS tracking, demonstrating processing speed and accuracy on modular external APIs.  
1.d) **Full System Simulation** (Putting It All Together): Combines overall functionality for real-world tests, like navigating with the hat. ANOVA compares scenarios. Using integrated visuals that show holistic metrics, charts combine all data (like errors and successes) to give a big-picture view of the hat's performance.

* **Mean Percentage Error**: The average mistake rate across tests, as a percentage. Example: Errors of 0.05, 0.08, and 0.06 average to 6.3%.

  Formula: errorsn×100

* **Success Percentage**: How often the hat gets things right. Example: 90 successes out of 100 \= 90%.

  Formula: ST×100

**Table 12**  
*Full System Simulation Metrics*

| Scenario | Mean Percentage Error (%) ± SD | Success Percentage (%) | ANOVA p-value (Across Scenarios) |
| :---- | ----- | ----- | ----- |
| Navigation |  |  |  |
| Text Reading |  |  |  |

Table 10 integrates mean percentage errors, success rates, and ANOVA p-values across scenarios (e.g., navigation vs. text reading) to evaluate the holistic performance full simulation of the navigation hat in end-to-end use.  
2\) Qualitative Data Presentation and Analysis   
The results will be presented in thematic summaries, quotes, and narratives (in appendices). Furthermore, the analysis will use inductive thematic coding to identify patterns in user feedback, focusing on emergent themes such as acclimation barriers and comfort enablers. Triangulation with quantitative data will occur via joint displays (e.g., matrices linking metrics to themes). Reliability will be ensured through member checking (e.g., user validation of themes) and inter-coder agreement.

2.a) Photogrammetry Performance: Quotes/summaries on acclimation; coding explores comfort/adaptation, linked to error rates.  
2.b) Gesture Command Responsiveness: Narratives/themes on ease; coding identifies barriers, integrated with accuracy scores.  
2.c) Modular AI and GPS Performance: Diaries/flowcharts for trajectories; coding assesses portability, correlated with FPS.  
2.d) Full System Simulation: Highlights/maps of experiences; synthesis triangulates with metrics for design refinement.

The researchers will integrate the quantitative and qualitative findings in the discussion section. In addition, the researchers will use simple side-by-side charts to illustrate how the hat's accuracy aligns with users' usage to display comprehensive insights, demonstrating significant performance improvements (p-values \< 0.05) and aligning with users' qualitative reports on device acclimation and overall functionality. Overall, this validates how efficient the navigation hat is as an artificial eye for people with vision impairments. The researchers will also address limitations (e.g., sample bias) and implications for future improvement of assistive technologies.

**Respondents of the Study**  
	The study will involve human participants for testing navigation on a controlled obstacle course, designed by the researchers, using the study’s wearable prototype called Stereo-based Sonification Interface System (Stesis). There will be 40 participants aged 18-30 years old, selected through purposive sampling within the university community to be recruited with conditions; good vision (14 participants) and mild (14 participants), moderate (10 participants), and blind (2 participants) visual impairments with good hearing condition. Participants with good vision will be blindfolded, for experimental control and pilot and evaluation testing, as the system is intended for visually impaired users. This sample size is appropriate for within-subject experimental design and paired statistical testing (Paired T-Test), ensuring adequate power to detect significant differences between State A and State B.
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

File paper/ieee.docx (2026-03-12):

World Navigation Hat: Development of a Wearable

Navigation Aid Using AIoT for the Visually Impaired

Jason C. D’Souza
Department of Computer Engineering
University of San Agustin
Iloilo City, Iloilo, Philippines
jdsouza@usa.edu.ph
ORCID: 0009-0003-6062-7921

Glenda Guanzon
Department of Computer Engineering
University of San Agustin
Iloilo City, Iloilo, Philippines
gguanzon@usa.edu.ph
Ethel Herna C. Pabito
Department of Computer Engineering
University of San Agustin
Iloilo City, Iloilo, Philippines
ehpabito@usa.edu.ph

Adha Theza R. Naputol
anaputol@usa.edu.ph
ChenLin Wang
Department of Computer Engineering
University of San Agustin
Iloilo City, Iloilo, Philippines
cwang@usa.edu.ph

Vince Ginno B. Daywan
Department of Computer Engineering
University of San Agustin
Iloilo City, Iloilo, Philippines
vgbalitao-saan@usa.edu.ph

Abstract— Over 2.2 billion people worldwide suffer from visual impairment. Conventional sensory substitution systems are ineffective due to sensory overload from unfilterable audio signals. To overcome this limitation, Stesis, a smart hat, was designed to mimic visual attention by enabling users to selectively filter data streams through intentional movement. When tested on forty participants in an obstacle course, the system showed marked improvements over conventional continuous proximity systems. By enabling users to control spatial audio, the system made repetitive physical scanning redundant. This resulted in a 59% reduction in physical effort and a 74% reduction in frustration. Although mental effort increased by 77% because of the dense audio processing, the overall mental workload decreased remarkably by almost 42%. Most importantly, travel efficiency and safety were greatly enhanced, as indicated by a 31% reduction in completion time and a 65% reduction in collision rates. Finally, the system clearly illustrates that controllable, high-density data is significantly better and provides a highly effective, low-frustration method for safe travel and object avoidance.

Keywords— Blindness, Accessibility, Mobility, Auditory, Independence

# I. Introduction

Visually impaired individuals are a significant concern for the global health community, with 2.2 billion people worldwide suffering from some form of visual impairment, and projected to rise to 2.5 billion by 2050 [1], with 2.17 million affected in the Philippines alone [2], [3]. Although the scope of visually impaired individuals varies from mild vision impairment to total blindness, the scope of this study is limited to the totally blind population, which comprises 43 million people worldwide, as stated by the World Health Organization (WHO) [1]. Total blindness significantly impairs an individual's ability to navigate the physical environment, access digital information, and maintain independence, leading to social isolation or disconnection [4]. These impacts are directly associated with the United Nations' 10th Sustainable Development Goal (SDG 10): Reduced Inequalities.

The blind population faces two intersecting layers of disparity. Disparities in navigation result from inaccessible physical and digital infrastructures, such as buildings without tactile Braille guides and digital platforms that lack comprehensive audio options [5]. Furthermore, social disparities manifest in communication bounds and labor market participation; statistics indicate that only 44% of the blind and severely visually impaired are employed, in stark contrast to the general population's 79% [6].

Current assistive technologies for the blind range from traditional mobility aids, including guide dogs and white canes, to electronic travel aids like Sensory Substitution Devices (SSDs) [7]. SSDs substitute one sensory expression into another, for the blind it’s by conveying visual geometry of an environment into auditory or tactile cues, allowing the blind user to achieve spatial awareness through alternative sensory modalities [8]. However, there are a number of significant barriers standing in the way of their widespread adoption. These include exhaustive training requirements, ergonomic discomfort, and most fundamentally, cognitive overload caused by the fact that non-visual senses have a significantly lower bandwidth for processing information than natural vision [9].

AIoT (Artificial Intelligence of Things) provides a solution in dealing with SSDs constraints like on navigating digital lives of users. AIoT is the integration of AI algorithms with IoT devices to build intelligent, autonomous systems [10], [11]. It enables wearable devices to use real-time processing of environmental information to forecast the user’s needs and provide adaptive and contextual responses, greatly enhancing the capabilities of navigation assistants [12]. Wearable devices, especially in the form of hats and glasses, provide hands-free assistance and encourage independence by effortlessly leveraging these connected sensors to translate visual information into spatial audio feedback [13], [14].

This paper introduces Stesis (Stereo-based Sonification Interface System), a novel wearable AIoT navigation hat that is specifically designed for the blind to overcome traditional SSD limitations. It utilizes a Raspberry Pi 4 architecture to process real-time stereo depth mapping, Stesis enables controlled and selective sensory substitution paired with a Radar mapping to deal with the bandwidth constraints between visual and audio senses, inspired by the natural selectivity of human visual perception [15]. Rather than constantly overwhelming the user with auditory information, the system enables users to control their sensory inputs through head movements, which significantly reduces cognitive overload, fatigue, and integration problems. This research aims to develop and test the empirical validity of a head-mounted AIoT prototype that serves as a highly modular and controllable “artificial eye” and “intuitive radar” to improve the real-world mobility of the blind.

## A. Research Objectives

The objective of this study is to develop an AIoT visual sensory substitution hat that minimizes sensory overload by allowing users to selectively filter environmental sonification. Specifically, to:

### 1) Develop a dual-mode prototype powered by a Raspberry Pi 4 that generates local depth maps via OpenCV stereo vision (Physical Mode) and integrates MediaPipe AI hand gesture recognition (Digital Mode).

### 2) Design a 3D-printed hat mount optimizing weight distribution, powered by a 10,000mAh bank, with modular NodeJS/ElectronJS server for AIoT integration.

### 3) Evaluate system and user performance using a within-subject design to test the impact of selective filtering on cognitive load and navigation efficiency against continuous streaming baselines.

# II. Related Work

Assistive technologies for visual impairment face fundamental challenges in providing environmental awareness without exceeding the low bandwidth of non-visual senses [5].
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

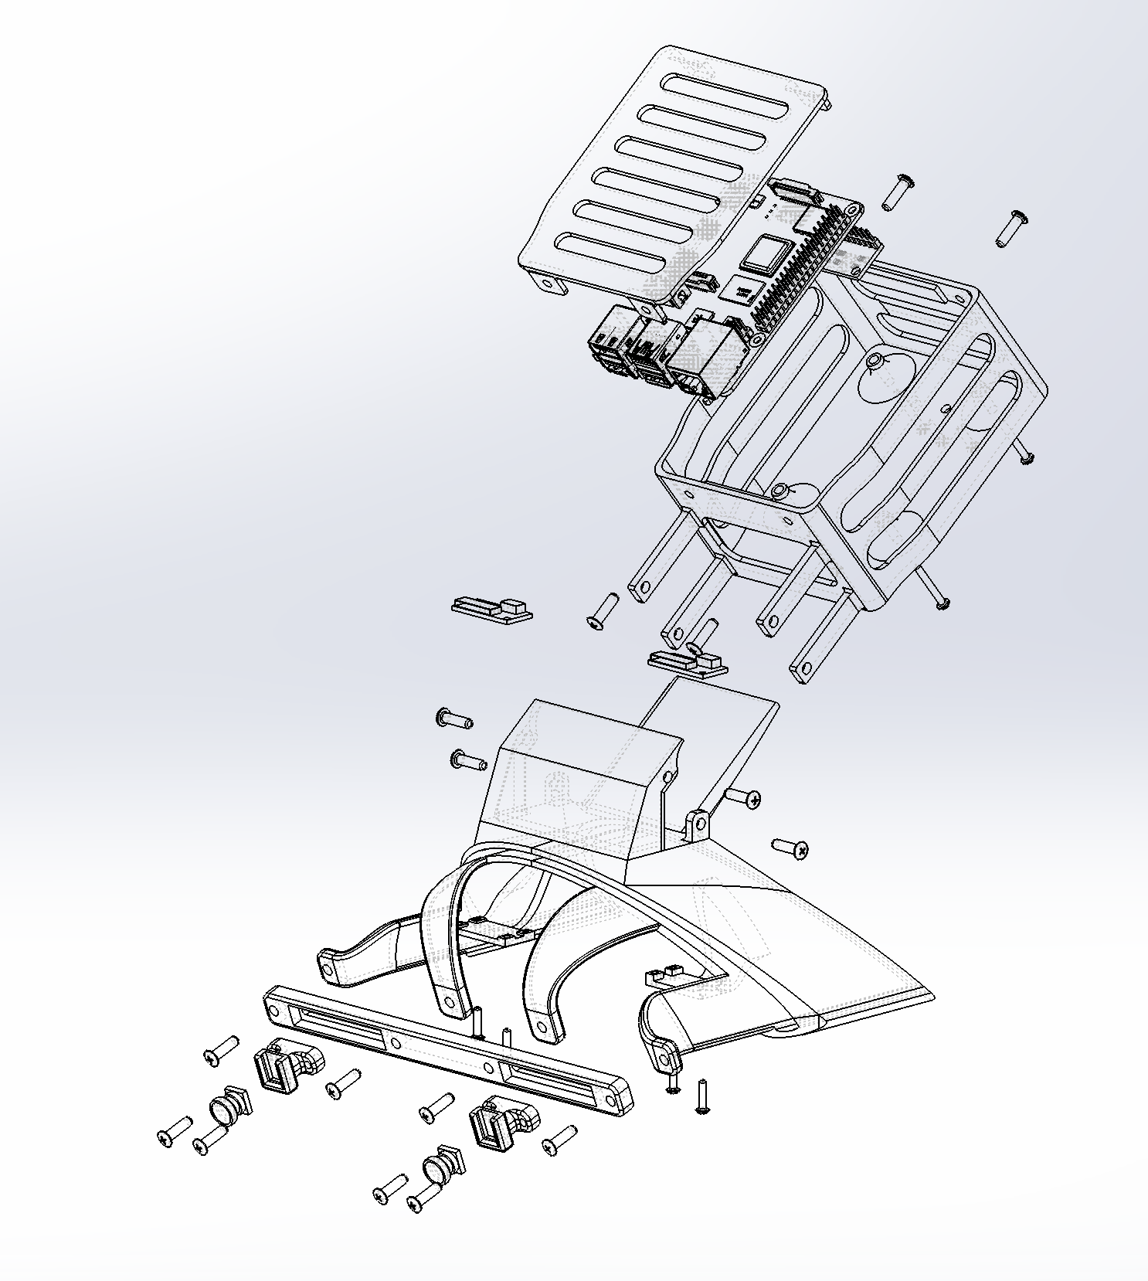
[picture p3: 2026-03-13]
design/images/Screenshot 2026-03-13 at 11.08.56 AM.png

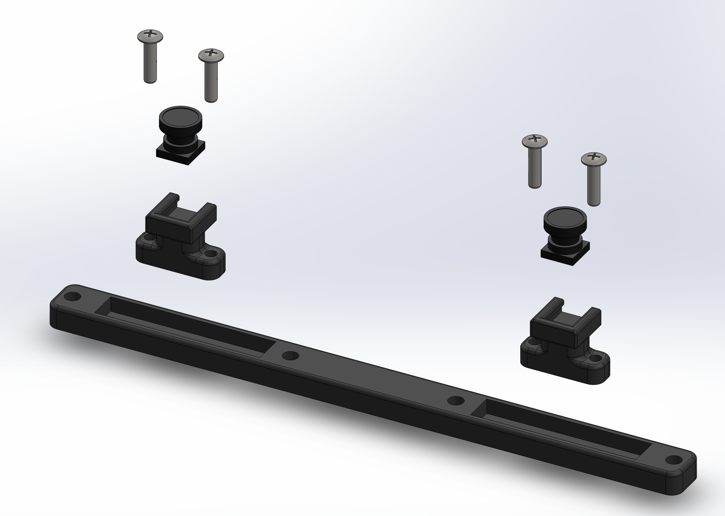
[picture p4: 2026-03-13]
design/images/Screenshot 2026-03-13 at 11.10.12 AM.png

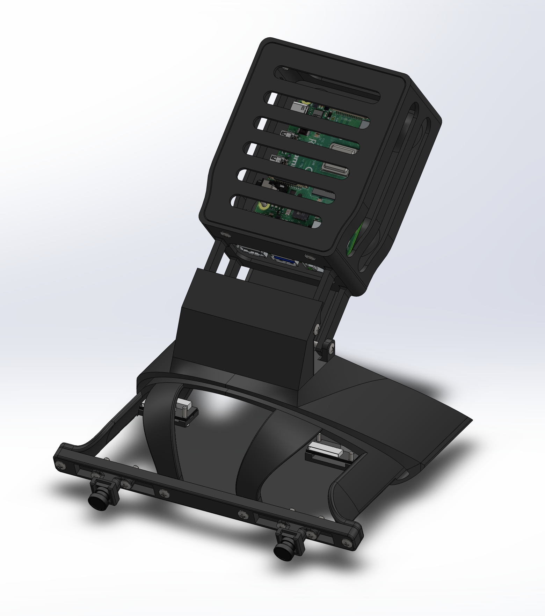
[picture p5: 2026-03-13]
design/images/Screenshot 2026-03-13 at 11.05.07 AM.png

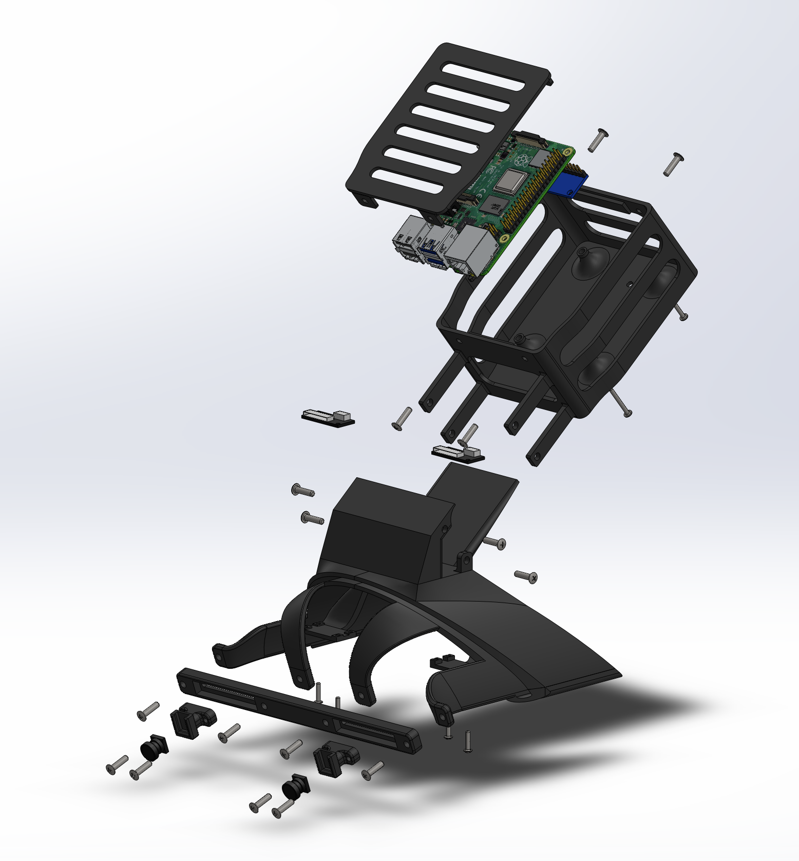
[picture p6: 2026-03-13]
design/images/Screenshot 2026-03-13 at 11.07.11 AM.png

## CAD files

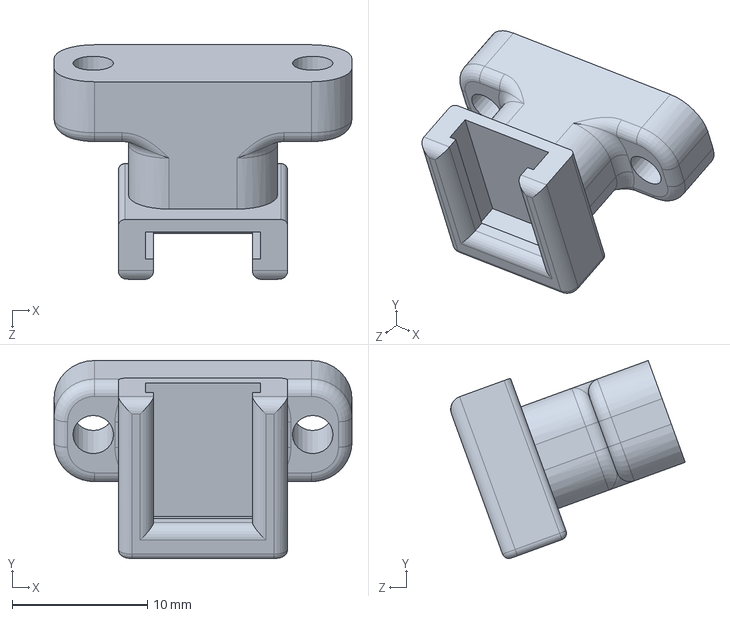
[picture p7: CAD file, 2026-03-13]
design/3d-models/Solidworks/main.SLDPRT
22.0 x 14.6 x 17.3 mm

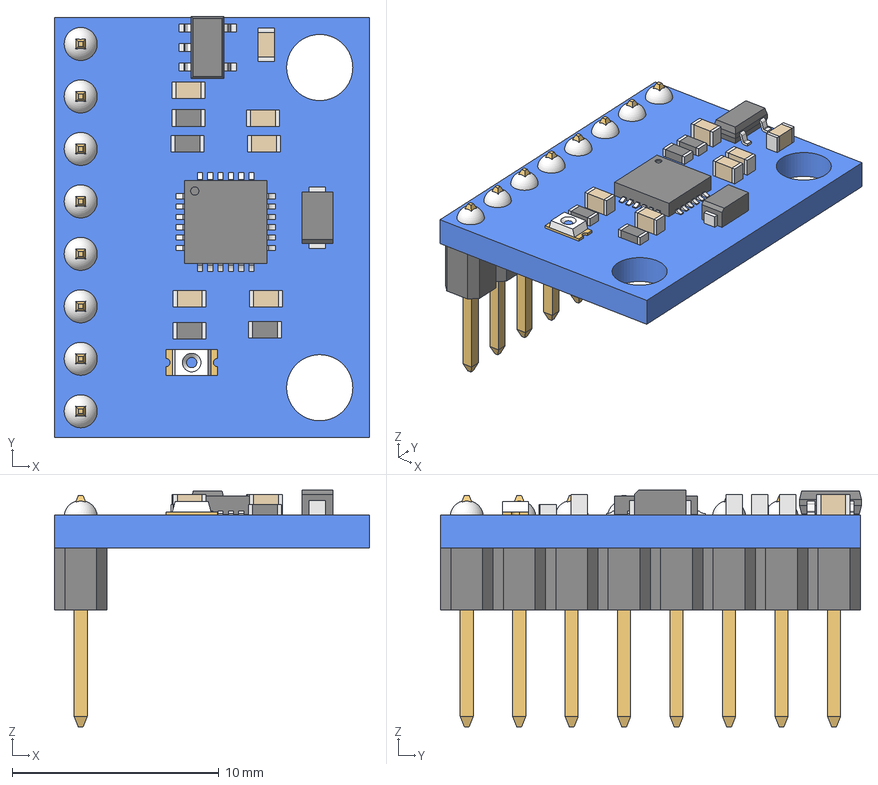
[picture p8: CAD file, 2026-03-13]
design/3d-models/Solidworks/mpu6050/mpu6050.step
15.3 x 20.4 x 11.5 mm
Board_001
SOT25_001
0603 Capacitor_001
0603 Capacitor_002
0603 Capacitor_003
0603 Capacitor_004
0603 Capacitor_005
0603 Capacitor_006
0603 Resistor_001
0603 Resistor_002
0603 Resistor_003
0603 Resistor_004
SM LED_001
Diode 2_001
24 QFN_001
1x8 Male Header_001

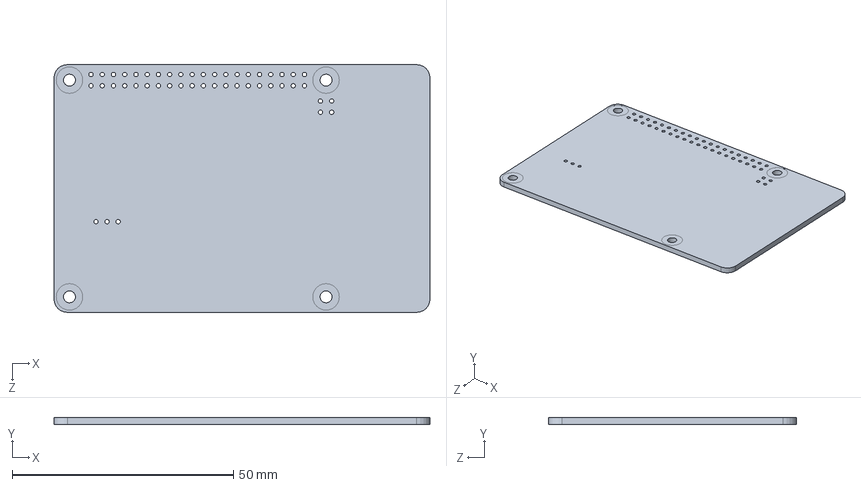
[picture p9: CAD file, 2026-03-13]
design/3d-models/Solidworks/raspberry-pi-4-model-b-1.snapshot.3/PCB, RPi4ModelB.SLDPRT
85.0 x 1.60 x 56.0 mm

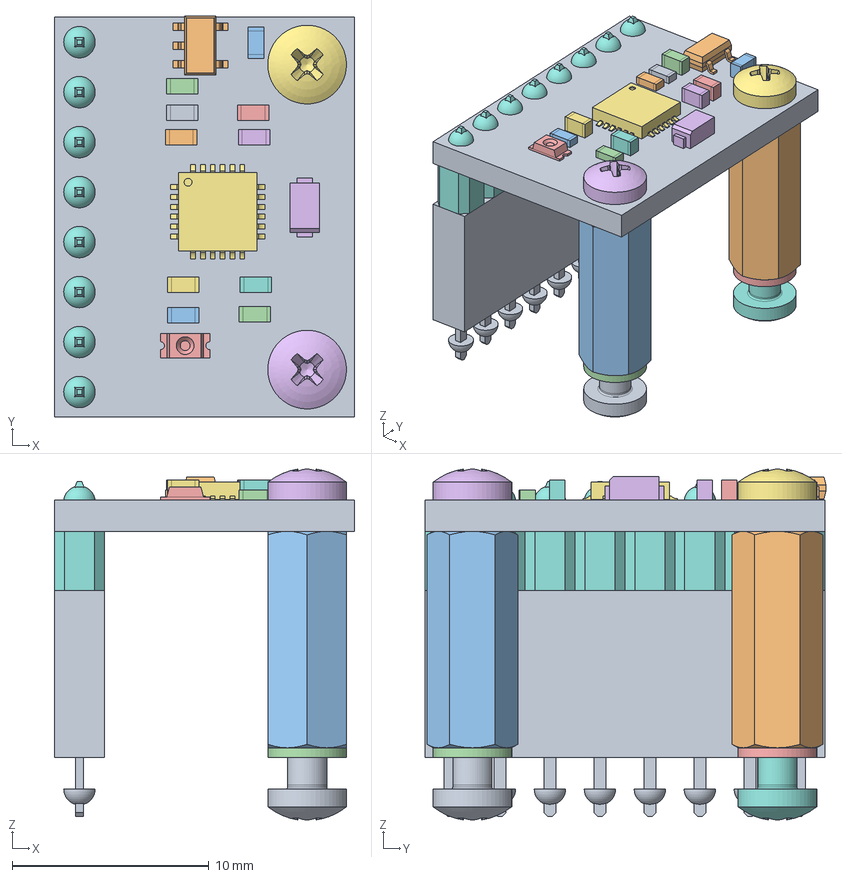
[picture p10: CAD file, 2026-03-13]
design/3d-models/Solidworks/mpu6050/FreeCAD Files/MPU6050 Module.FCStd
15.3 x 20.4 x 17.8 mm
Board_001
SOT25_001
0603 Capacitor_001
0603 Capacitor_002
0603 Capacitor_003
0603 Capacitor_004
0603 Capacitor_005
0603 Capacitor_006
0603 Resistor_001
0603 Resistor_002
0603 Resistor_003
0603 Resistor_004
SM LED_001
Diode 2_001
24 QFN_001
1x8 Male Header_001
8 Pos Socket Header_001
M2 x 11 Nylon Standoff_001
M2 x 11 Nylon Standoff_002
M2 Nylon Flat Washer_001
M2 Nylon Flat Washer_002
M2 x 5 Nylon Screw_001
M2 x 5 Nylon Screw_002
M2 x 5 Nylon Screw_003
M2 x 5 Nylon Screw_004

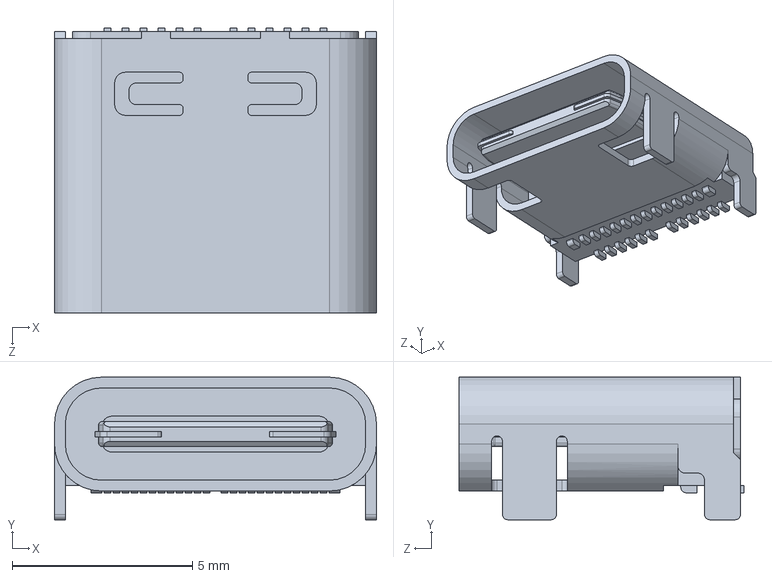
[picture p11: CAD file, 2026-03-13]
design/3d-models/Solidworks/raspberry-pi-4-model-b-1.snapshot.3/Female USB Type C Connector, RPi4ModelB.SLDPRT
8.94 x 3.96 x 7.90 mm

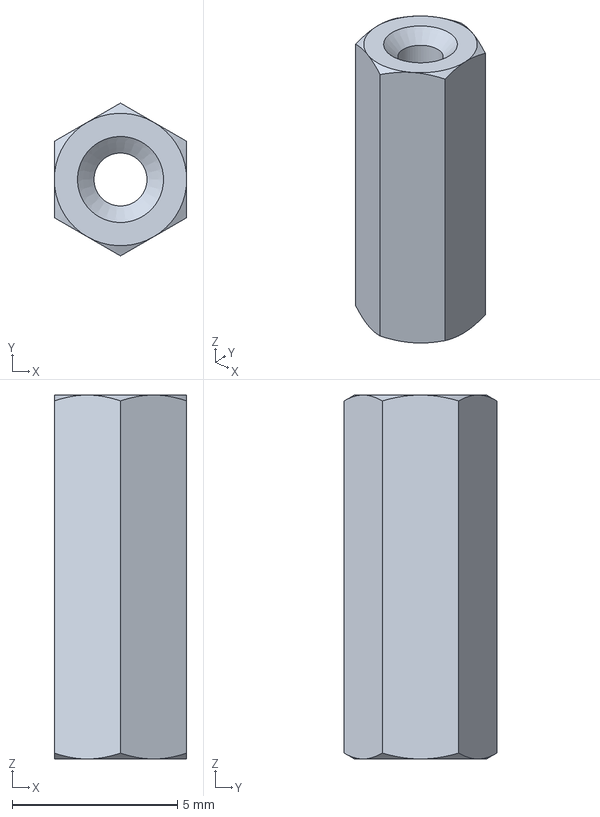
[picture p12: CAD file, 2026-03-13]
design/3d-models/Solidworks/mpu6050/FreeCAD Files/M2 x 11 Nylon Standoff.FCStd
4.00 x 4.62 x 11.0 mm

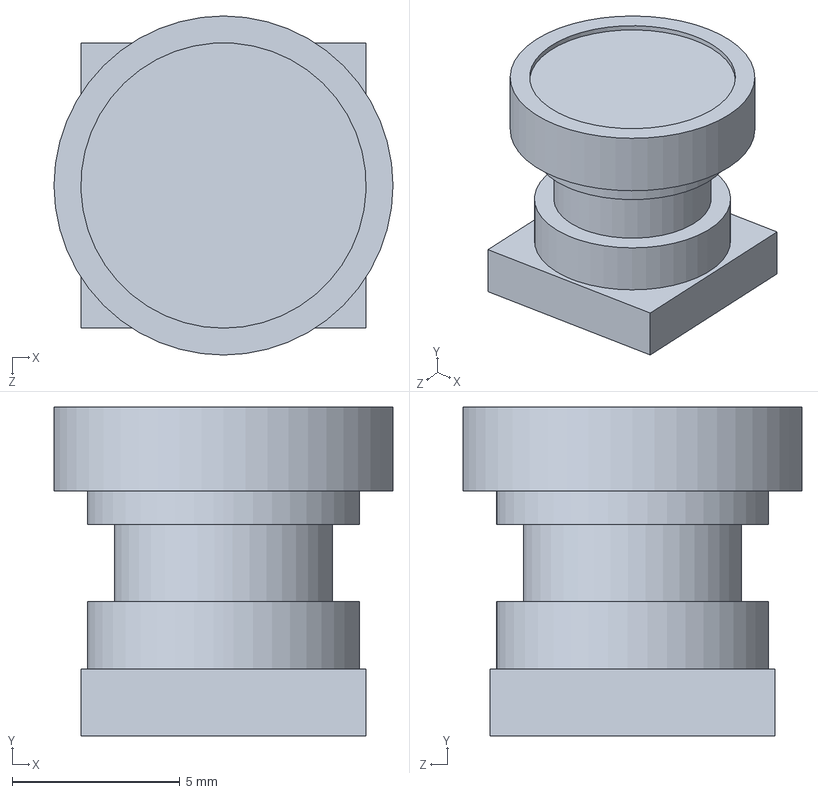
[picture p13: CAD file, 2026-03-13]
design/3d-models/Solidworks/OV5640-camera.SLDPRT
10.1 x 9.80 x 10.1 mm

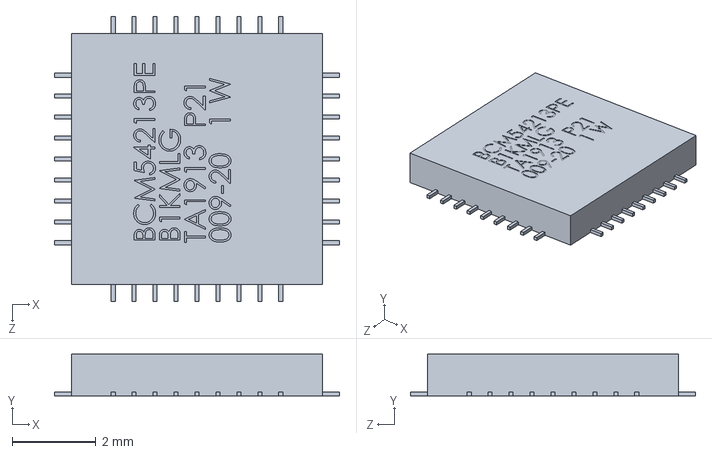
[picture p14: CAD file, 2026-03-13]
design/3d-models/Solidworks/raspberry-pi-4-model-b-1.snapshot.3/Broadcom BCM54213PE Gigabit Ethernet Transceiver, RPi4ModelB.SLDPRT
6.80 x 1.00 x 6.80 mm

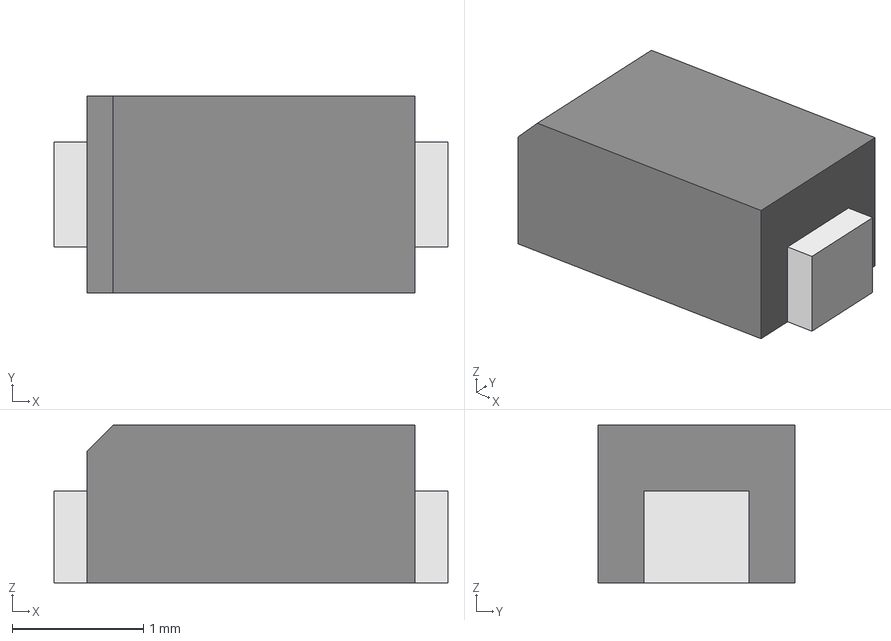
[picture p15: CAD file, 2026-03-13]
design/3d-models/Solidworks/mpu6050/FreeCAD Files/Diode 2.FCStd
3.00 x 1.50 x 1.20 mm
Body001 (Mirror #1)

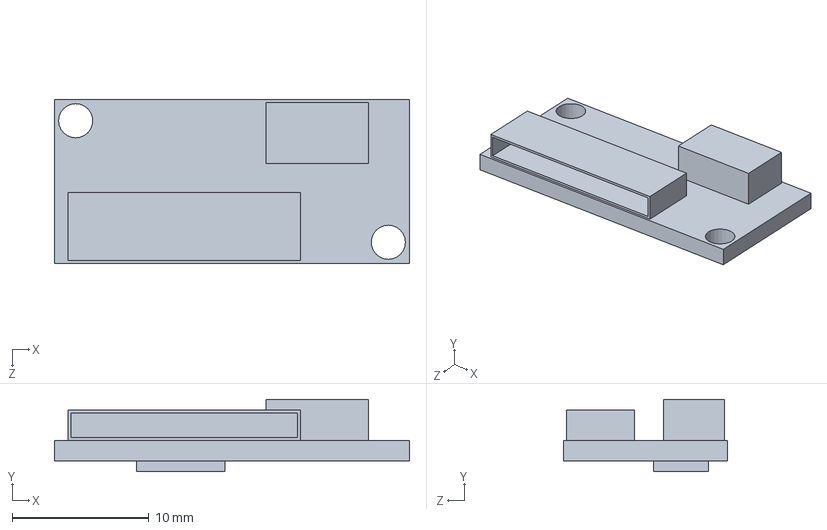
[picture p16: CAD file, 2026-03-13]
design/3d-models/Solidworks/OV5640-pcb.SLDPRT
26.0 x 5.30 x 12.0 mm

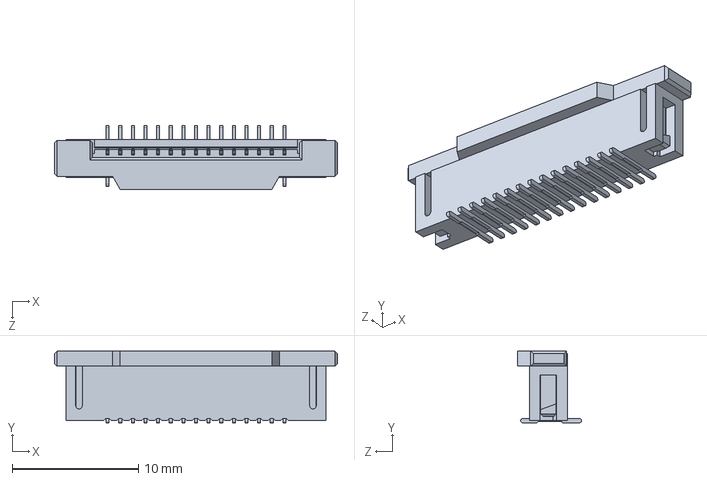
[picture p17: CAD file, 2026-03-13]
design/3d-models/Solidworks/raspberry-pi-4-model-b-1.snapshot.3/Camera Connector, RPi4ModelB.SLDPRT
22.4 x 5.68 x 5.07 mm

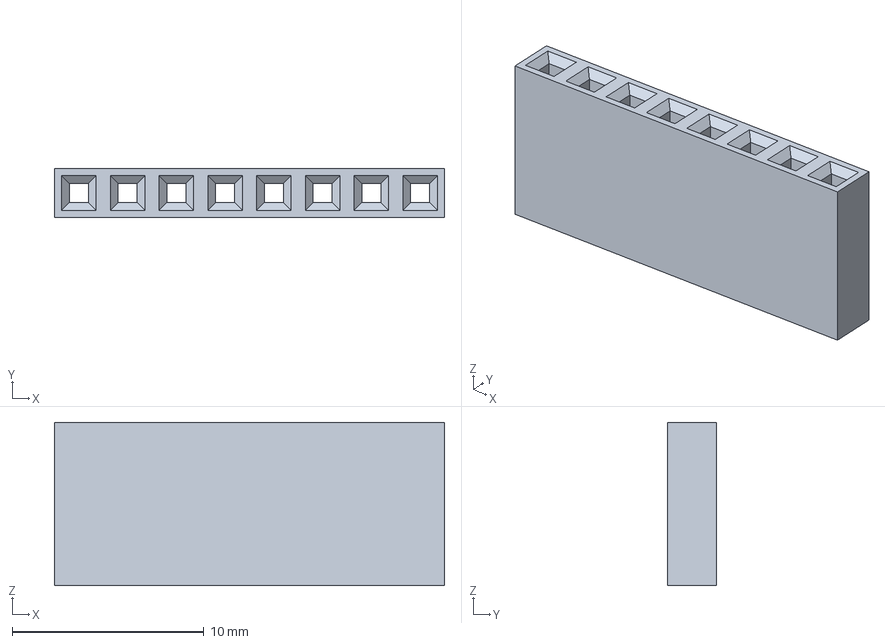
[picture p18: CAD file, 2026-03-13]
design/3d-models/Solidworks/mpu6050/FreeCAD Files/8 Pos Socket Header.FCStd
20.3 x 2.54 x 8.50 mm

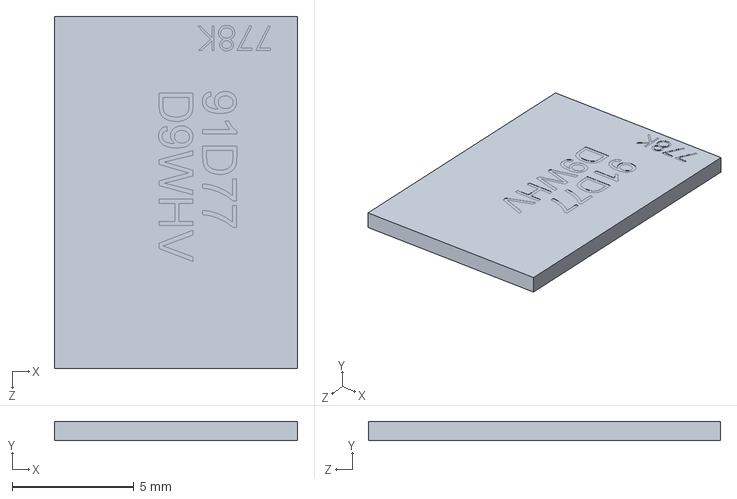
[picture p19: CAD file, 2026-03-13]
design/3d-models/Solidworks/raspberry-pi-4-model-b-1.snapshot.3/91D77 D9WHV 778K, 4 GB LPDDR4 SDRAM, RPi4ModelB.SLDPRT
10.0 x 0.8 x 14.5 mm

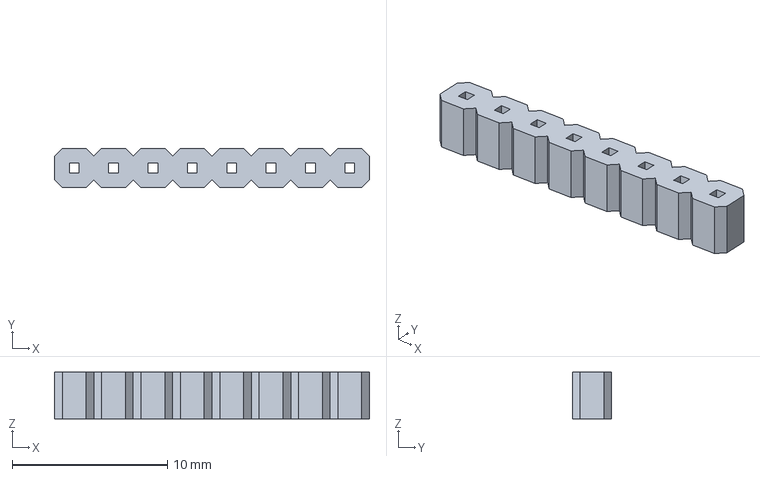
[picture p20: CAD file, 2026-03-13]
design/3d-models/Solidworks/mpu6050/FreeCAD Files/1x8 Male Header.FCStd
20.3 x 2.54 x 3.00 mm

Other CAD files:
design/3d-models/Solidworks/camera-assem-exploded.SLDASM
design/3d-models/Solidworks/camera-assem.SLDASM
design/3d-models/Solidworks/raspberry-pi-4-model-b-1.snapshot.3/Raspberry Pi 4 Model B.SLDASM
design/3d-models/Solidworks/box.SLDPRT
design/3d-models/Solidworks/draws/with_frame/camera-draws-solid.SLDDRW
design/3d-models/Solidworks/draws/with_frame/camera-draws.SLDDRW
design/3d-models/Solidworks/draws/with_frame/main-draws-solid.SLDDRW
design/3d-models/Solidworks/draws/with_frame/main-draws.SLDDRW
design/3d-models/Solidworks/draws/without_frame/camera-draws-solid.SLDDRW
design/3d-models/Solidworks/draws/without_frame/camera-draws.SLDDRW
design/3d-models/Solidworks/draws/without_frame/main-draws-solid.SLDDRW
design/3d-models/Solidworks/draws/without_frame/main-draws.SLDDRW
design/3d-models/Solidworks/mpu6050/FreeCAD Files/0603 Capacitor.FCStd
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

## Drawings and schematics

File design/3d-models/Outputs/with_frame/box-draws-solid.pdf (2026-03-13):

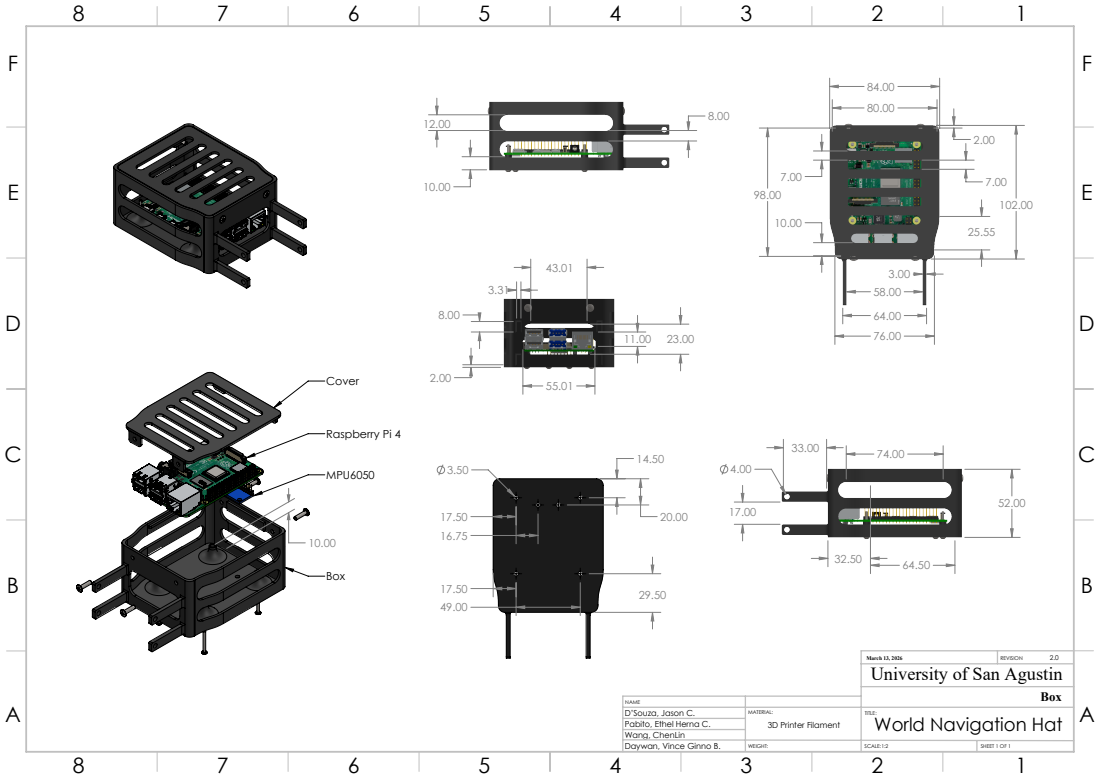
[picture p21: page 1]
Raspberry Pi 4; March 13, 2026; REVISION; SCALE:1:2; SHEET 1 OF 1

University of San Agustin

NAME
D’Souza, Jason C. | MATERIAL: 3D Printer Filament | TITLE: World Navigation Hat

Pabito, Ethel Herna C.
Wang, ChenLin
Daywan, Vince Ginno B.

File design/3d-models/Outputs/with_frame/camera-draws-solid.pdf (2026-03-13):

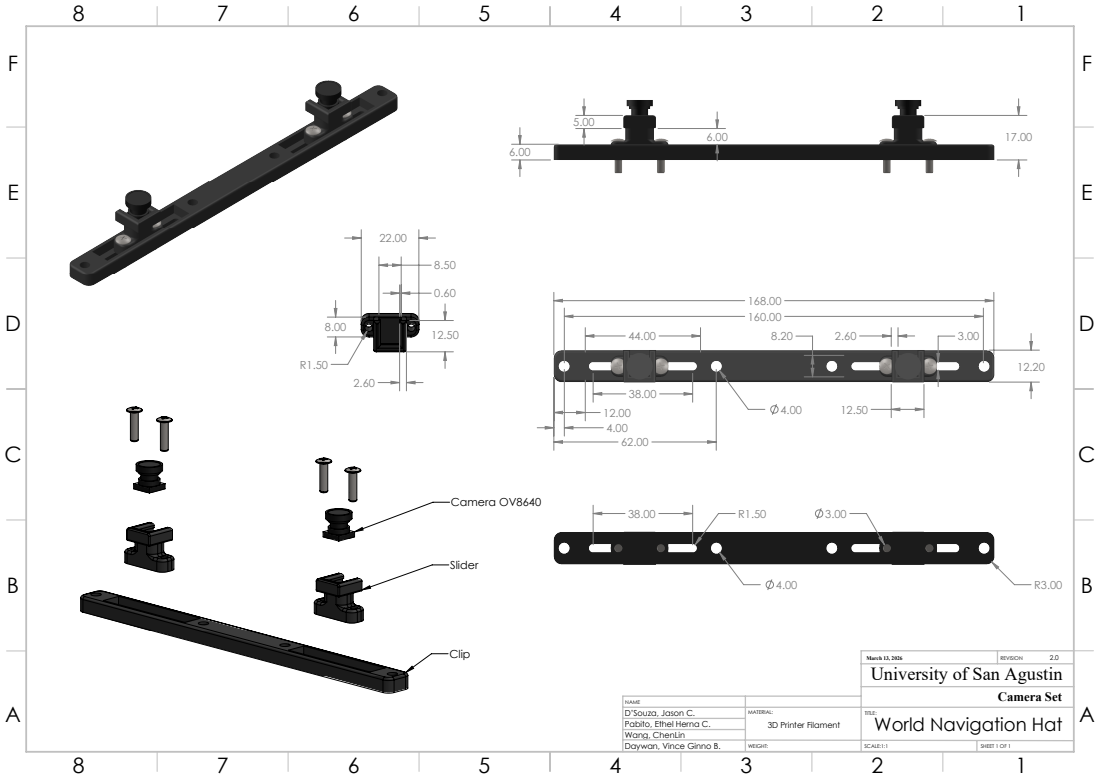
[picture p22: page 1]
Camera OV8640; March 13, 2026; REVISION; SCALE:1:1; SHEET 1 OF 1; Camera Set

University of San Agustin

NAME
D’Souza, Jason C. | MATERIAL: 3D Printer Filament | TITLE: World Navigation Hat

Pabito, Ethel Herna C.
Wang, ChenLin
Daywan, Vince Ginno B.

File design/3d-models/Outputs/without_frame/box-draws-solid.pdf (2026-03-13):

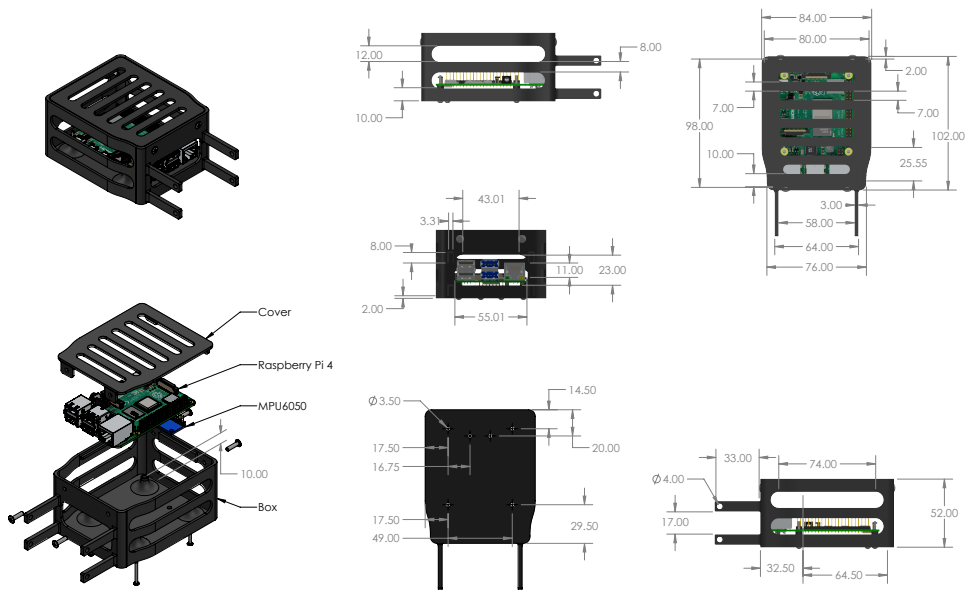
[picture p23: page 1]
Raspberry Pi 4

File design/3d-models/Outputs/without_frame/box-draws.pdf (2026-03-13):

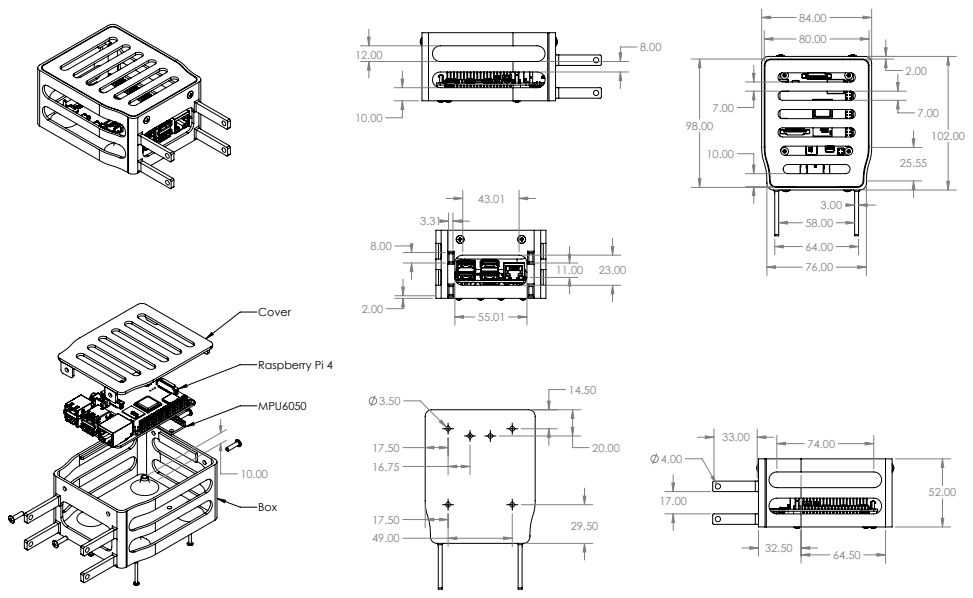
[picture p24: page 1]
Raspberry Pi 4

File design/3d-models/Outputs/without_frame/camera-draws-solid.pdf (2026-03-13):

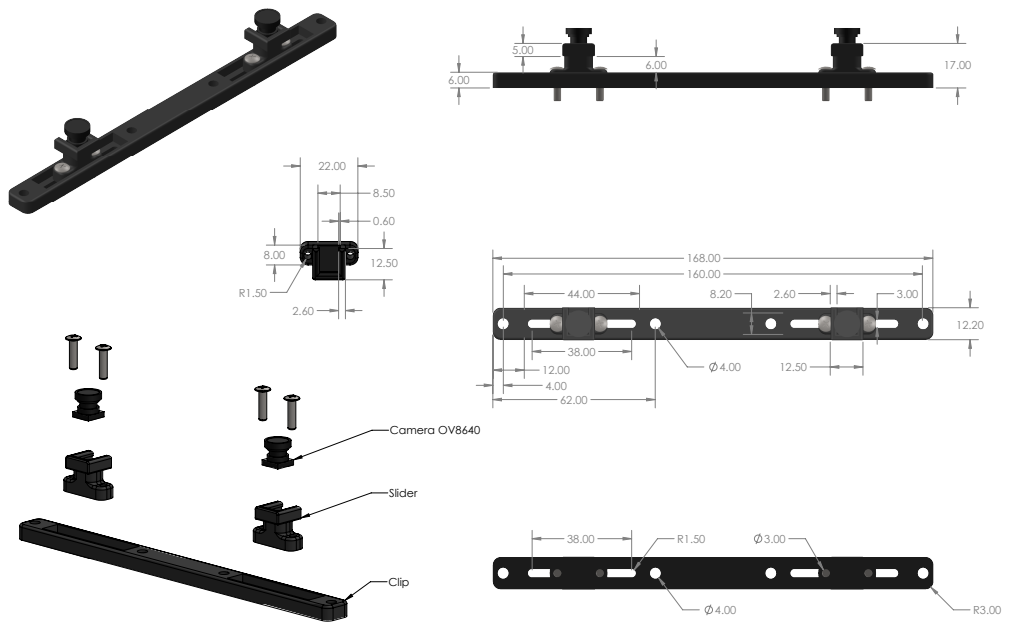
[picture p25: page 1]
Camera OV8640

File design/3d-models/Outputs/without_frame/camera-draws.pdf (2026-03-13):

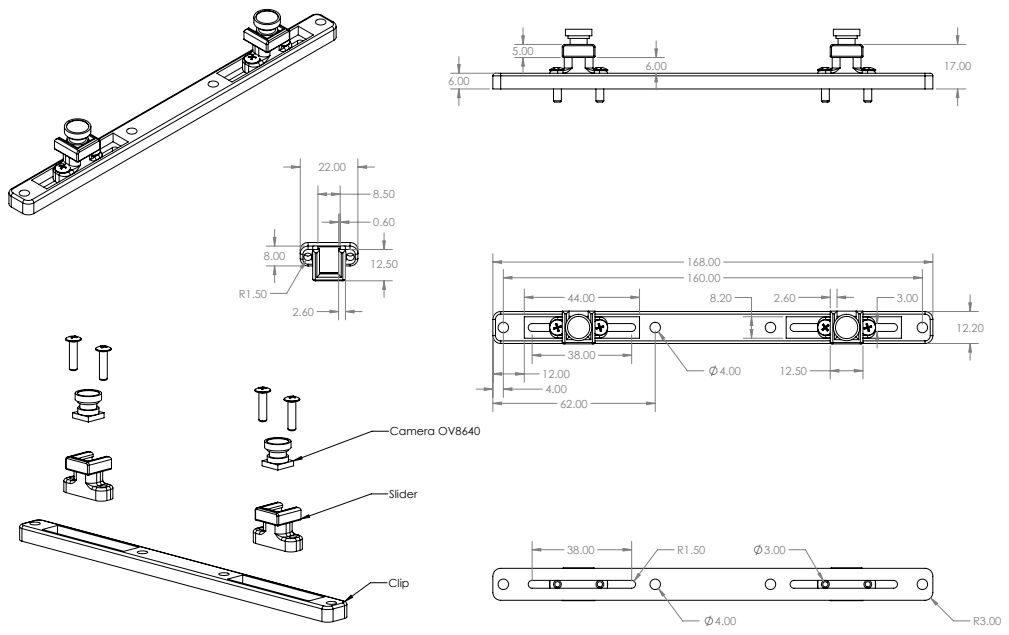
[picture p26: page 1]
Camera OV8640

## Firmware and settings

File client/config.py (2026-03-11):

import cv2
import numpy as np

class Config:
    # MAIN
    DOMAIN = 8080               # Port of server
    HOST = '0.0.0.0'            # Host of server

    # CAMERA: camera.py - Use `v4l2-ctl --list-devices` to find cameras
    CAM_ID_LEFT = 2             # /dev/video{ID} of left camera
    CAM_ID_RIGHT = 0            # /dev/video{ID} of right camera
    WIDTH = 640                 # Input video width
    HEIGHT = 480                # Input video height
    SCALE = 0.5                 # Camera scaled to improve performance
    
    # IMU
    ACCEL_DEADBAND = 0.05       # Simple deadband filter for accelerometer noise
    VELOCITY_DECAY = 0.95       # Friction/Decay factor to stop drift when no motion
    IMU_ADDR = 0x68             # IMU I2C Address

    # CALIBRATION
    BASELINE = 13.0             # Distance between left and right camera in CM
    CHECKERBOARD_DIMS = (9, 6)  # Calibration board dimensions
    SQUARE_SIZE_CM = 2.9        # Calibration board square size in CM
    AUTO_CAPTURE_DELAY = 2.0    # Automatic calibration capture delay in Seconds
    MOVEMENT_THRESHOLD = 3.0    # Movement treshold to stop/break automatic calibration in Seconds
    POST_CAPTURE_COOLDOWN = 2.0 # Cooldown after capture to continue automatic capture in Seconds

    # DEPTHMAP
    USE_WLS = True              # Enable WLS for cleaner depth map?
    MIN_DISPARITY = 0           #
    NUM_DISPARITIES = 16*3      #
    BLOCK_SIZE = 5              #

    # RADAR
    LEFT_OFFSET = 80            # Pixels to ignore on the left edge of the depth map
    RING_UNIT = 100             # Distance between radar rings in CM
    SPEED_THRESHOLD_CM = 10.0   # Change per frame to trigger green motion dots in CM
    BOUNCE_SWEEP = True         # Radar bouce after hitting sides instead of restarting?
    ENABLE_MOTION_DETECTION = False # Include motion detection in radar?
    SWEEP_SPEED_SEC = 2.0       # Time taken for a single sweep from both ends in Seconds
    RADAR_FADE = 0.93
    MAX_RADAR_DIST_CM = 300
    FOV_H = 60.0              
    RADAR_RING_COLOR = (255, 255, 0) # Cyan (BGR) - For Max/Min Volume Circles
    RADAR_GRID_COLOR = (150, 150, 150) # Light Gray - For grid rings and FOV lines
    RADAR_TEXT_SCALE = 0.3      # Text size multiplier

    # AUDIO SONIFICATION
    SPECTRO_HEIGHT = 200             # Pixel height of the bottom graphs
    SPECTRO_TIME_HISTORY_SEC = 3.0   # How many seconds the graph width represents
    AUDIO_SMOOTHING_COEFF = 0.8      # 0.0 (No smoothing) to 0.99 (Heavy smoothing)
    AUDIO_BASE_FREQ = 200.0          # Frequency (Hz) for max distance (300cm)
    AUDIO_MAX_FREQ = 1200.0          # Frequency (Hz) for min distance (0cm)
    PLAY_AUDIO = True                # Toggle to output sound to speakers
    AUDIO_SAMPLE_RATE = 44100        # Audio sample rate
    AUDIO_CHUNK_SIZE = 1024          # Buffer size for audio chunks
    AUDIO_MODE = 'DISTANCE_VERTICAL' # Options: 'DISTANCE_VERTICAL' or 'DISTANCE'
    MAX_VOL_DIST_CM = 50.0           # Inner boundary: 100% Volume (Cyan circle)
    MIN_VOL_DIST_CM = 250.0          # Outer boundary: 0% Volume (Gray circle)

    def __init__(self):
        self.gui = np.zeros((500, 500, 3), dtype=np.uint8)
        self.key = 0
        self.width = int(self.WIDTH*self.SCALE)
        self.height = int(self.HEIGHT*self.SCALE)

    # Intialize resources
    def setup(self):
        pass

    # Repeated every frame
    def loop(self):
        pass

    # On exit
    def cleanup(self):
        cv2.destroyAllWindows()

    def render(self):
        cv2.imshow(f"Stesis {self.__class__.__name__}", self.gui)

    # Main function
    def run(self):
        print(f"Starting {self.__class__.__name__}...")
        running = True
        if self.setup(): running = False
        try:
            while running:
                self.key = cv2.waitKey(1) & 0xFF
                running = not self.loop()
                self.render()
                if self.key == ord('q'): break
        except KeyboardInterrupt:
            print("\nStopped by user.")
        finally:
            self.cleanup()
            print(f"{self.__class__.__name__} cleanup done.")

if __name__ == "__main__":
    app = Config()
    app.run()

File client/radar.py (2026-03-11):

import cv2
import numpy as np
import math
import time
from depth import Depth
#from imu import IMU

class Radar(Depth):
    def __init__(self):
        super().__init__()
        
        # Radar State
        self.radar = None 
        self.prev_distances = None
        self.last_sweep_x = self.LEFT_OFFSET
        self.sweep_range_width = 0
        self.last_radar_time = time.time()
        
        # Output State
        self.radar_view = None
        
        # Audio/Logic State (Exposing for Audio class)
        self.sw_x = 0
        self.sw_dist = 0
        self.sw_y = 0
        self.mot_dist = 0
        self.mot_x = 0
        self.mot_y = 0
        self.valid_sweep = False

    def setup(self):
        super().setup() # Init IMU, Camera, Depth
        print("Initializing Radar...")

        self.radar = np.zeros((self.height, self.width, 3), dtype=np.uint8)
        self.prev_distances = np.zeros(self.width)
        self.sweep_range_width = self.width - self.LEFT_OFFSET - 1 

    @staticmethod
    def polar_to_cartesian_yaw_corrected(cx, cy, dist_cm, angle_deg, current_yaw, max_dist, canvas_radius):
        global_angle = current_yaw + angle_deg
        r = (dist_cm / max_dist) * canvas_radius
        r = min(r, canvas_radius)
        angle_rad = math.radians(global_angle - 90)
        x = int(cx + r * math.cos(angle_rad))
        y = int(cy + r * math.sin(angle_rad))
        return x, y

    def loop(self):
        if super().loop(False): return True

        curr_time = time.time()
        dt = curr_time - self.last_radar_time
        self.last_radar_time = curr_time
        
        if self.disparity is None: return

        # Radar Logic
        disparity_clean = np.where(self.disparity > 0, self.disparity, 0)
        disparity_clean[:, :self.LEFT_OFFSET] = 0 
        
        self.radar = cv2.addWeighted(self.radar, self.RADAR_FADE, np.zeros_like(self.radar), 0.0, 0)
        radar_cx, radar_cy = self.width // 2, self.height // 2
        canvas_radius = min(self.width, self.height) // 2 - 10
        
        current_distances = np.zeros(self.width)
        current_y_coords = np.zeros(self.width, dtype=int)
        
        closest_motion_dist = self.MAX_RADAR_DIST_CM
        motion_x = -1
        motion_y = -1
        
        # --- DISTANCE & MOTION DETECTION ---
        for sx in range(self.LEFT_OFFSET, self.width):
            col_disp = disparity_clean[:, sx]
            max_y = np.argmax(col_disp)
            max_d = col_disp[max_y]
            
            if max_d > 0:
                dist_cm = (self.focal_length * self.BASELINE) / max_d
                current_distances[sx] = dist_cm
                current_y_coords[sx] = max_y
                
                if self.ENABLE_MOTION_DETECTION and self.prev_distances[sx] > 0:
                    speed = abs(dist_cm - self.prev_distances[sx])
                    if speed > self.SPEED_THRESHOLD_CM:
                        col_angle_local = ((sx / self.width) * self.FOV_H) - (self.FOV_H / 2)
                        rx_m, ry_m = self.polar_to_cartesian_yaw_corrected(
                            radar_cx, radar_cy, dist_cm, col_angle_local, self.yaw, 
                            self.MAX_RADAR_DIST_CM, canvas_radius
                        )
                        cv2.circle(self.radar, (rx_m, ry_m), 4, (0, 255, 0), -1)
                        
                        if dist_cm < closest_motion_dist:
                            closest_motion_dist = dist_cm
                            motion_x = sx
                            motion_y = max_y

        self.prev_distances = current_distances.copy()
        
        # --- SWEEP LOGIC ---
        if self.BOUNCE_SWEEP:
            cycle_time = 2.0 * self.SWEEP_SPEED_SEC
            sweep_progress = (curr_time % cycle_time) / self.SWEEP_SPEED_SEC
            if sweep_progress <= 1.0:
                curr_sweep_x = self.LEFT_OFFSET + int(sweep_progress * self.sweep_range_width)
            else:
                curr_sweep_x = self.LEFT_OFFSET + int((2.0 - sweep_progress) * self.sweep_range_width)
        else:
            sweep_progress = (curr_time % self.SWEEP_SPEED_SEC) / self.SWEEP_SPEED_SEC
            curr_sweep_x = self.LEFT_OFFSET + int(sweep_progress * self.sweep_range_width)
            
        if not self.BOUNCE_SWEEP and curr_sweep_x < self.last_sweep_x:
            sweep_range = list(range(self.last_sweep_x, self.width)) + list(range(self.LEFT_OFFSET, curr_sweep_x))
        elif self.BOUNCE_SWEEP and curr_sweep_x < self.last_sweep_x:
            sweep_range = range(self.last_sweep_x, curr_sweep_x, -1)
        else:
            sweep_range = range(self.last_sweep_x, curr_sweep_x)
            
        closest_sweep_dist = self.MAX_RADAR_DIST_CM
        closest_sweep_y = self.height // 2
        valid_sweep = False

        for sx in sweep_range:
            if sx >= self.width or sx < self.LEFT_OFFSET: continue
            dist_cm = current_distances[sx]
            
            if dist_cm > 0:
                valid_sweep = True
                y_val = current_y_coords[sx]
                
                if dist_cm < closest_sweep_dist:
                    closest_sweep_dist = dist_cm
                    closest_sweep_y = y_val
                
                g = int(255 * (1.0 - (y_val / (self.height - 1))))
                color = (0, g, 255) # BGR
                
                col_angle_local = ((sx / self.width) * self.FOV_H) - (self.FOV_H / 2)
                rx, ry = self.polar_to_cartesian_yaw_corrected(
                    radar_cx, radar_cy, dist_cm, col_angle_local, self.yaw, 
                    self.MAX_RADAR_DIST_CM, canvas_radius
                )
                cv2.circle(self.radar, (rx, ry), 2, color, -1)
                
        self.last_sweep_x = curr_sweep_x
        
        # Save state for Audio
        self.sw_x = curr_sweep_x
        self.sw_dist = closest_sweep_dist
        self.sw_y = closest_sweep_y
        self.mot_dist = closest_motion_dist
        self.mot_x = motion_x
        self.mot_y = motion_y
        self.valid_sweep = valid_sweep
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

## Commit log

2026-03-05 0.0.15 - Presentation init
    [model.FCStd]
2026-03-06 0.0.13 - Prototype demo
2026-03-12 0.0.17 - Build from USB
    [model.FCStd]
2026-03-13 0.0.18.1 (pdf) made 3d measurements.
    [0603 Capacitor.FCStd, 0603 Resistor.FCStd, 1x8 Male Header.FCStd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]
